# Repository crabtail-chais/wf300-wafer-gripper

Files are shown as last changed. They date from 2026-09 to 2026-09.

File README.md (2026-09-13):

# WF300 — 300 mm 双手晶圆夹取治具

Open hardware for a two-hand, edge-contact 300 mm wafer gripper.

**P1D1 工程试制设计 / Engineering prototype. 尚未完成实物资格验证，不能凭本仓库直接放行真实工艺晶圆使用。**

Assembly geometry — schematic only

本项目公开双手持握、水平低速转移晶圆的机械设计、尺寸图、BOM 和生产装配说明。它不是安全双手联锁，也不是 FOUP 取片器、吸盘或平桌铲片工具。

## 从哪里开始

1. 阅读 [安全边界与未关闭事项](SAFETY.md) 和 [公开版说明](docs/PUBLICATION.md)。
2. 查看 [12 页 A3 尺寸图](drawings/WF300-DH_P1D1_drawings.pdf) 与 [11 页生产装配说明](docs/WF300-DH_P1D1_assembly_manual.pdf)。
3. 下载 [闭合 FreeCAD 模型](cad/WF300-DH_P1D1_closed.FCStd)、[全开模型](cad/WF300-DH_P1D1_open.FCStd) 或 [闭合 STEP](cad/WF300-DH_P1D1_closed.step)。
4. 加工评审使用 [5 种自制件 STEP](parts_step)、[BOM](manufacturing/BOM_P1D1.csv)、[紧固连接记录](manufacturing/16个紧固连接与扭矩记录.csv) 和 [首件验收记录](manufacturing/首件验收记录.csv)。空白记录不代表合格。

## 设计边界

| 项目 | P1D1 基线 |
| --- | --- |
| 晶圆 | Ø300 mm；厚度 0.50–0.90 mm，参考片 0.775 mm |
| 接触 | 正反面最外缘 2 mm 内允许接触；四个未填充 PEEK 槽块 |
| 结构材料 | 6061-T651 框架、316L 导杆/端盖、A4-70 螺钉 |
| 采购件 | Ensinger TECAPEEK SX natural；igus JSM-1012-20；Lee Spring LP024K05S316；TE 31090 |
| 单侧行程 | 8 ± 0.20 mm，待首件检验 |
| 开启力目标 | 每手横向开启增量 2–5 N，峰值 ≤5 N；不含托举自重 |
| 洁净 / ESD 意图 | Class 100 左右 / ISO 5 操作区；金属独立接地、工位离子化；不是认证 |
| 使用假设 | 干态、水平、低速，20–25°C、40%–55% RH，无凝露、有防跌托盘 |

数值是需求、设计值或开发目标，不是实测合格结果。装配说明提供材料、表处、压装、线束、清洗、停点、检查及操作程序；任何代料或尺寸修改都需要重新验证。

## 文件组织

| 目录 | 内容 |
| --- | --- |
| `cad/` | 闭合 / 全开 FCStd 与 STEP，含简化采购件和参考晶圆 |
| `parts_step/` | 左右框架、槽块、导杆、端盖的局部坐标 STEP |
| `drawings/` | 12 页 PDF 及逐页 SVG / DXF |
| `manufacturing/` | 13 行 BOM、16 连接记录、首件验收表、公开来源链接 |
| `docs/` | 中文装配说明、版本范围与验证状态 |
| `tools/` | 无第三方依赖的只读文件校验工具，不是建模器或 CAM |
| `validation/` | 公开文件来源与哈希；不含内部详细测试记录 |

DXF 使用**纸面毫米**，标注由线、箭头和文字组成，不是关联式尺寸，不能直接当作 1:1 CAM。加工以经工程和工艺人员签署的关键二维尺寸、公差和要求为准，同版 STEP 补充复杂轮廓；矛盾需提偏差评审。

## 打开与校验

CAD 原件保留既有几何与对象结构。自制件为可编辑实体，不承诺完整草图约束或全参数生成历史。原生螺钉重算依赖 [FreeCAD Fasteners Workbench](https://github.com/shaise/FreeCAD_FastenersWB)，历史版本为 `79a06dc067b57ebc89532be835704eb2af5da96c`；没有该插件时，可使用 STEP 查看几何。

Python 3.10+，在仓库根目录运行：

```sh
python3 tools/verify_release.py
python3 -m unittest discover -s tests -v
```

这只检查发布文件、哈希、容器结构、BOM 数量及明显的本机路径/凭证模式，不会执行 CAD 内部 Python 对象，不会重算几何，也不会给制造、洁净、ESD 或晶圆安全放行。校验失败时退出码非零。

## 验证状态与贡献

装配说明引用了历史 CAD 检查结论；详细内部测试报告不属于本仓库的公开范围，因此不能仅凭本仓库独立复核这些历史结论。此次公开整理没有重跑依赖原工作环境的几何检查，也没有新增实片测试。详见 [验证状态](docs/VALIDATION.md)。

欢迎贡献制造可行性、人体工学、颗粒 / ESD 数据、减重设计和真正可重建的参数模型。请附版本、单位、假设、方法和原始证据，区分仿真与测量，见 [CONTRIBUTING](CONTRIBUTING.md)。

## 许可

项目权利范围内：硬件设计、图纸和 BOM 使用 **CERN-OHL-P-2.0**；独立软件使用 **MIT**；说明文档使用 **CC BY 4.0**。适用范围见 [LICENSING](LICENSING.md)，第三方工具和品牌见 [THIRD_PARTY_NOTICES](THIRD_PARTY_NOTICES.md)。均不构成供应商背书或适用性保证。

---

### English summary

WF300 is an unqualified engineering prototype for two-hand, horizontal handling of 300 mm wafers, 0.50–0.90 mm thick, with permitted contact within the outer 2 mm of both faces. It includes native FreeCAD files, STEP models, dimensioned drawings, a BOM, and Chinese manufacturing/assembly instructions. Cleanliness, ESD, operating forces, damage risk, and service life remain unqualified. Read [SAFETY](SAFETY.md) before any physical trial. The portable verifier checks release integrity, not mechanical safety. Hardware: CERN-OHL-P-2.0; software: MIT; documentation: CC BY 4.0, subject to the scope and third-party notices above.

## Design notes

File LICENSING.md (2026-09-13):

# Licence scope

Publication date: 2026-09-13. Project attribution: **crabtail-chais and contributors**.

The following licences apply to rights held by the project licensors. They do not relicense third-party software, standards, trademarks, catalogue documents or any rights the licensors do not hold.

| Files / material | Licence |
| --- | --- |
| `cad/`, `parts_step/`, `drawings/`, `manufacturing/` excluding `sources.json`; design geometry in `assets/` | [CERN-OHL-P-2.0](LICENSES/CERN-OHL-P-2.0.txt) |
| Project-authored `tools/`, `tests/` and any future project-authored CI configuration | [MIT](LICENSES/MIT.txt) |
| README, safety/contribution/publication/validation documentation, `validation/` records, `manufacturing/sources.json` | [CC BY 4.0](LICENSES/CC-BY-4.0.txt) |
| Licence texts, third-party notices and referenced external material | Their respective terms; see [notices](THIRD_PARTY_NOTICES.md) |

Copyright (c) 2026 crabtail-chais and contributors, to the extent copyright subsists and is held by those licensors. AI assistance was used in developing and documenting this engineering prototype; this notice does not assert exclusivity over public facts, standards, or non-copyrightable material.

The native FCStd files intentionally retain their exact historical bytes for model-to-drawing traceability. Their generic saved **“All rights reserved”** document property predates this release and is superseded, for the project-owned material in the files, by the explicit CERN-OHL-P-2.0 grant in this repository. This does not remove or override third-party rights. Carry this scope notice and applicable notices with redistributed source or products as required by the licences.

No endorsement by CERN, FreeCAD, tool developers, or suppliers is implied. Commercial reuse is allowed under the applicable licence conditions; there is no representation of patent clearance, cleanroom qualification, or fitness for a particular wafer process.

Licence references: [CERN official licence page](https://cern-ohl.web.cern.ch/), [Creative Commons BY 4.0](https://creativecommons.org/licenses/by/4.0/), [SPDX licence list](https://spdx.org/licenses/). Full texts are included under `LICENSES/`; the root `LICENSE` is the hardware licence.

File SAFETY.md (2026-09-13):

# 安全边界 / Safety and qualification status

**This is an unqualified engineering prototype, not a production-qualified wafer-handling device. CAD checks are not physical safety tests.**

截至 P1D1 发布基线，尚无实际首件测量、合格扭矩窗口、污染、晶圆损伤、ESD 或耐久验证结果。开源发布不改变工程准入状态。以下为工程警示和建议，不是在开源许可证之外增加用途限制。

## 制造与试验停点

- 图纸需由设计、加工、工艺和质量人员评审，尤其是表处后孔径、四点共面、PEEK 槽唇、端盖、有效螺纹和滑动配合。
- 0.08 / 0.20 / 0.15 N·m 是三类接头的试验起点，不是批准装配扭矩；需在同材料、表处和有效啮合条件下确定窗口。
- 弹簧、衬套和端子为简化几何，采购按准确料号和验收规范，不能制造这些包络体代替采购件。TE 端子实物接口和压接工艺仍需核验。
- 使用前须完成空载、假片厚度边界、偏载 / 单侧动作、力—行程、接头保持、颗粒、金属 / 离子污染及 ESD 检验。真实工艺片准入须现场责任人另行批准。
- 用防跌托盘及受控支撑进行试验；不得在悬空晶圆上调螺钉或拆弹簧。双手柄没有安全联锁功能。

## 不能从当前结果推导的结论

- 开启力 2–5 N/手不等于低自重或人体工学合格；持握载荷、疲劳、防滑、线束拖力需独立评估。
- Class 100 / ISO 5 是操作环境意图，未证明治具动态产尘符合要求。工艺污染限值仍需由实际使用方给定。
- 金属到公共点 ≤1 Ω、离子平衡与晶圆表面电位各 ±10 V 是开发目标。绝缘 PEEK / iglidur 不能单靠金属接地消电；离子器读数不等于晶圆读数；不承诺绝对 0 V。
- 合格接地路径需现场 ESD 负责人批准，不能短接人员腕带安全电阻。
- 100 / 1000 次是开发筛查节点，不是寿命额定值。
- 不覆盖热片、湿片、真空、竖直或冲击搬运、FOUP、平桌铲片与自动化设备联锁。

事故、损伤或污染异常时先让载台承托晶圆，停止并隔离治具。请以不含客户晶圆图像、工艺机密或个人信息的方式报告风险；敏感细节不要直接发到公开 issue。

Provided as-is, without warranty. The licences and notices describe the legal terms; this page records engineering limitations rather than certification.

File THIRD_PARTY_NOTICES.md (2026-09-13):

# Third-party provenance and exclusions

## CAD tooling

The historical engineering files were produced with FreeCAD / Open CASCADE. Sixteen ISO 4762 screw representations were generated using [FreeCAD Fasteners Workbench](https://github.com/shaise/FreeCAD_FastenersWB), commit `79a06dc067b57ebc89532be835704eb2af5da96c` (ScrewMaker: Ulrich Brammer; workbench wrapper: Shai Seger and contributors).

The upstream workbench [declares GPLv2](https://github.com/shaise/FreeCAD_FastenersWB/blob/79a06dc067b57ebc89532be835704eb2af5da96c/LICENSE). Its program source, icons and distributions are **not bundled or relicensed as MIT here**. The native files contain generated shapes, module/class references and serialized parameter data, not a vendored workbench implementation. Project licence grants are limited to project-controlled design rights; use of a GPL tool does not itself establish that every generated output is GPL-licensed. See upstream terms for the tool. No general legal clearance opinion is made.

Other development plugins, workstation-specific validator implementations and detailed historical test reports are not redistributed. Tool references in the assembly documentation are attribution, not endorsement of this project by those developers.

## Purchased components and standards

Ensinger, igus, Lee Spring, Bossard, TE Connectivity and Outokumpu names identify proposed materials or publicly documented components. They remain their owners' names and marks. No manufacturer has certified this assembly through this publication. Availability, price, exact screw order codes and suitability require independent confirmation.

Spring envelopes, installed bush dimensions and terminal tongues are project-made simplified representations, **not downloaded manufacturer CAD**. They omit physical details and are not production models for those purchased parts.

The repository links to public catalogue/standards sources in [sources.json](manufacturing/sources.json) and the assembly manual. It does not distribute supplier PDF originals, proprietary CAD downloads, ISO/SEMI standard texts, private quotations, supplier contact lists or internal budgets. Dimensions and factual source references do not grant rights to copy the linked documents.

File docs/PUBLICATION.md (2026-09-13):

# P1D1 公开版范围与历史文档勘误

公开版整理日期：2026-09-13。设计版次仍为 **P1D1**，不是新的机械修订版。

## 未改变的内容

2 个 FCStd、2 个装配 STEP、5 个自制件 STEP、24 个带标注 SVG / DXF、12 页图纸 PDF、11 页装配说明 PDF、装配说明 Markdown 和制造表单均保留原件字节。没有重画、减重或改变尺寸、公差、采购选型及安全门槛。逐项原始和发布哈希见 [provenance.json](../validation/provenance.json)。

FCStd 内历史默认许可证字段未修改，以免破坏其已有哈希绑定；项目权利人的本次显式开源授权及优先适用说明见 [LICENSING](../LICENSING.md)。

## 新增和脱敏

新增公开 README、安全边界、许可、第三方来源说明、贡献指南、只读校验工具和测试。公开范围限于设计、图纸、BOM、装配说明、许可及可移植代码。详细内部测试结果、数值校验报告和历史日志未纳入，文件来源表也不索引这些未公开报告；不改写失败为通过。

## 阅读历史装配说明时的适用说明

原 PDF / Markdown 中关于 `source/`、`evidence/`、`qa/`、旧会话、初次失败截图以及“没有对外发送”的文字描述的是**工程交付时点**，不代表当前仓库的目录、可复现性或发布状态。本说明对公开目录和复现范围的描述优先；机械技术要求未被改写。

| 历史描述 | 公开版实际内容 |
| --- | --- |
| `source/` 可复现流程 | 旧生成器依赖历史会话、本机插件及固定路径，首版不纳入。原生 CAD 是当前设计源文件；不是从零参数重建承诺。 |
| `evidence/`、`qa/` 及初次失败截图 | 不在公开范围；只保留文件来源 / 哈希及验证状态说明。装配说明中的历史检查结论不等于本仓库提供了完整的公开复核证据。 |
| 原始投影 SVG | 仅保留逐页带尺寸图和装配等轴预览，不纳入庞大中间投影数据。 |
| 旧 R2、选型中间版、询价 / 预算材料 | 不属于首个公开基线，避免版本混用和内部商业信息披露。 |

历史几何验证的范围和不能推出的结论见 [VALIDATION](VALIDATION.md)。本次公开 QA 只决定文件是否适合公开，不是机械制造或真实晶圆使用批准。

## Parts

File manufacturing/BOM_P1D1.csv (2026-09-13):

item | part_number | description | quantity | material_source
01 | WF300-P1-FRAME-L | 左框架 | 1 | 6061-T651 / CNC，批准加工厂
02 | WF300-P1-FRAME-R | 右框架 | 1 | 6061-T651 / CNC，批准加工厂
03 | WF300-P1-PAD | 槽块 | 4 | TECAPEEK SX natural / Ensinger原料
04 | WF300-P1-ROD | 阶梯导杆 | 2 | 316L / CNC+精磨，材料批次证明
05 | WF300-P1-CAP | 叉形端盖 | 4 | 316L / 一体车铣
06 | JSM-1012-20 | 导向衬套 | 4 | igus / iglidur J
07 | LP024K05S316 | 压缩弹簧 | 4 | Lee Spring / Type316 ASTM A313
08 | ISO4762-M3x12 | 槽块螺钉 | 8 | A4-70 / Bossard BN612优先
09 | ISO4762-M4x10 | 端盖螺钉 | 4 | A4-70 / Bossard BN612优先
10 | ISO4762-M3x6 | 接地螺钉 | 4 | A4-70 / Bossard BN612优先
11 | TE 31090 | 治具端子 | 4 | TE SOLISTRAND / 铜镀锡
12 | WF300-P1-WIRE | 接地线材裁件 | 4 | 22AWG PTFE，1000±20 / 按规范采购
13 | TE 31090 | 远端端子 | 4 | TE / 线束远端，不在CAD内

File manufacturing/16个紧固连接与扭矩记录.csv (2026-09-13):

joint | object | type | spec | contact | thread_host | nominal_engagement_mm | test_start_Nm | approved_torque_window | actual_torque_Nm | operator | tool_id | inspection | recheck_24h | recheck_1000cycles
J01 | CAP_SCREW_1_L | K2 | M4x10 | END_COLLAR_1_L | GUIDE_ROD_1 | 7 | 0.2 | 未实测/不得当作起始扭矩直接放行
J02 | CAP_SCREW_1_R | K2 | M4x10 | END_COLLAR_1_R | GUIDE_ROD_1 | 7 | 0.2 | 未实测/不得当作起始扭矩直接放行
J03 | CAP_SCREW_2_L | K2 | M4x10 | END_COLLAR_2_L | GUIDE_ROD_2 | 7 | 0.2 | 未实测/不得当作起始扭矩直接放行
J04 | CAP_SCREW_2_R | K2 | M4x10 | END_COLLAR_2_R | GUIDE_ROD_2 | 7 | 0.2 | 未实测/不得当作起始扭矩直接放行
J05 | GROUND_SCREW_FRAME_L | K3 | M3x6 | GROUND_LUG_FRAME_L | LEFT_CARRIAGE | 5.16 | 0.15 | 未实测/不得当作起始扭矩直接放行
J06 | GROUND_SCREW_FRAME_R | K3 | M3x6 | GROUND_LUG_FRAME_R | RIGHT_CARRIAGE | 5.16 | 0.15 | 未实测/不得当作起始扭矩直接放行
J07 | GROUND_SCREW_ROD_1 | K3 | M3x6 | GROUND_LUG_ROD_1 | GUIDE_ROD_1 | 5.16 | 0.15 | 未实测/不得当作起始扭矩直接放行
J08 | GROUND_SCREW_ROD_2 | K3 | M3x6 | GROUND_LUG_ROD_2 | GUIDE_ROD_2 | 5.16 | 0.15 | 未实测/不得当作起始扭矩直接放行
J09 | PAD_SCREW_01_1 | K1 | M3x12 | PEEK_PAD_01 | RIGHT_CARRIAGE | 4 | 0.08 | 未实测/不得当作起始扭矩直接放行
J10 | PAD_SCREW_01_2 | K1 | M3x12 | PEEK_PAD_01 | RIGHT_CARRIAGE | 4 | 0.08 | 未实测/不得当作起始扭矩直接放行
J11 | PAD_SCREW_02_1 | K1 | M3x12 | PEEK_PAD_02 | RIGHT_CARRIAGE | 4 | 0.08 | 未实测/不得当作起始扭矩直接放行
J12 | PAD_SCREW_02_2 | K1 | M3x12 | PEEK_PAD_02 | RIGHT_CARRIAGE | 4 | 0.08 | 未实测/不得当作起始扭矩直接放行
J13 | PAD_SCREW_03_1 | K1 | M3x12 | PEEK_PAD_03 | LEFT_CARRIAGE | 4 | 0.08 | 未实测/不得当作起始扭矩直接放行
J14 | PAD_SCREW_03_2 | K1 | M3x12 | PEEK_PAD_03 | LEFT_CARRIAGE | 4 | 0.08 | 未实测/不得当作起始扭矩直接放行
J15 | PAD_SCREW_04_1 | K1 | M3x12 | PEEK_PAD_04 | LEFT_CARRIAGE | 4 | 0.08 | 未实测/不得当作起始扭矩直接放行
J16 | PAD_SCREW_04_2 | K1 | M3x12 | PEEK_PAD_04 | LEFT_CARRIAGE | 4 | 0.08 | 未实测/不得当作起始扭矩直接放行

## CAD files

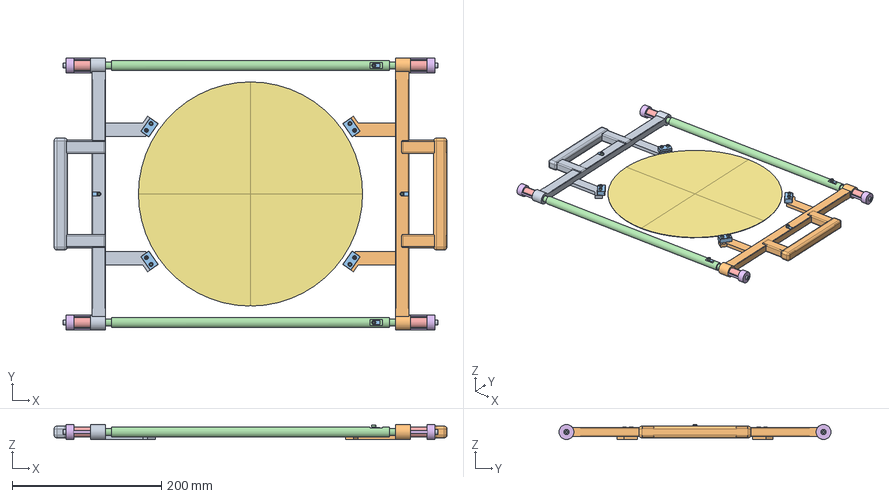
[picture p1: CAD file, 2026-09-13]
cad/WF300-DH_P1D1_open.step
526.0 x 364.0 x 20.0 mm
Left handle-carriage
Right handle-carriage
PEEK edge-capture pad 1
PEEK edge-capture pad 2
PEEK edge-capture pad 3
PEEK edge-capture pad 4
P1 one-piece stepped rod 1
LP024K05S316 1L — simplified envelope, NOT coil CAD
LP024K05S316 1R — simplified envelope, NOT coil CAD
R2 forked cap 1-L / positive opening stop
R2 forked cap 1-R / positive opening stop
P1 one-piece stepped rod 2
LP024K05S316 2L — simplified envelope, NOT coil CAD
LP024K05S316 2R — simplified envelope, NOT coil CAD
R2 forked cap 2-L / positive opening stop
R2 forked cap 2-R / positive opening stop
Reference wafer — 300 mm
M3x12-Screw x 8
M4x10-Screw
M4x10-Screw010
M4x10-Screw011
M4x10-Screw012
BUSH_1_L
BUSH_2_L
BUSH_1_R
BUSH_2_R
GROUND_LUG_FRAME_L
M3x6-Screw x 2
GROUND_LUG_FRAME_R
GROUND_LUG_ROD_1
M3x6-Screw005
GROUND_LUG_ROD_2
M3x6-Screw006

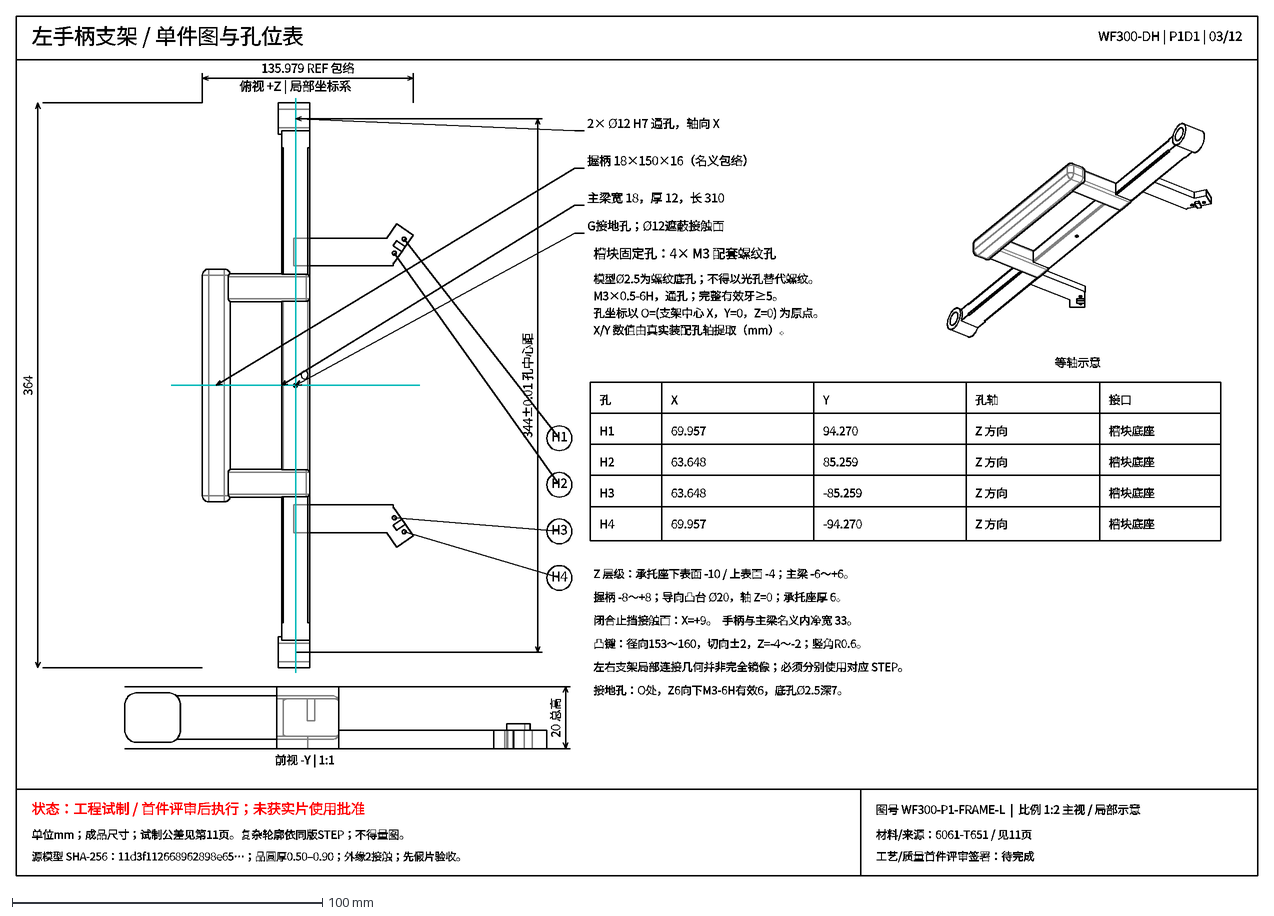
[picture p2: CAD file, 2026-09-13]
drawings/03_WF300-P1-FRAME-L.dxf
左手柄支架 / 单件图与孔位表
WF300-DH | P1D1 | 03/12
状态：工程试制 / 首件评审后执行；未获实片使用批准
单位mm；成品尺寸；试制公差见第11页。复杂轮廓依同版STEP；不得量图。
源模型 SHA-256：11d3f112668962898e65…；晶圆厚0.50–0.90；外缘2接触；先假片验收。
图号 WF300-P1-FRAME-L | 比例 1:2 主视 / 局部示意
材料/来源：6061-T651 / 见11页
工艺/质量首件评审签署：待完成
俯视 +Z | 局部坐标系
364
344±0.01 孔中心距
135.979 REF 包络
O
2× Ø12 H7 通孔，轴向 X
握柄 18×150×16（名义包络）
主梁宽 18，厚 12，长 310
20 总高
前视 -Y | 1:1
等轴示意
槽块固定孔：4× M3 配套螺纹孔
模型Ø2.5为螺纹底孔；不得以光孔替代螺纹。
M3×0.5-6H，通孔；完整有效牙≥5。
孔坐标以 O=(支架中心 X，Y=0，Z=0) 为原点。
X/Y 数值由真实装配孔轴提取（mm）。
孔
X
Y
孔轴
接口
H1
69.957
94.270
Z 方向
槽块底座
H2
63.648
85.259
H3
-85.259
H4
-94.270
Z 层级：承托座下表面 -10 / 上表面 -4；主梁 -6～+6。
握柄 -8～+8；导向凸台 Ø20，轴 Z=0；承托座厚 6。
闭合止挡接触面：X=+9。 手柄与主梁名义内净宽 33。
凸键：径向153～160，切向±2，Z=-4～-2；竖角R0.6。
左右支架局部连接几何并非完全镜像；必须分别使用对应 STEP。
接地孔：O处，Z6向下M3-6H有效6，底孔Ø2.5深7。
G接地孔；Ø12遮蔽接触面

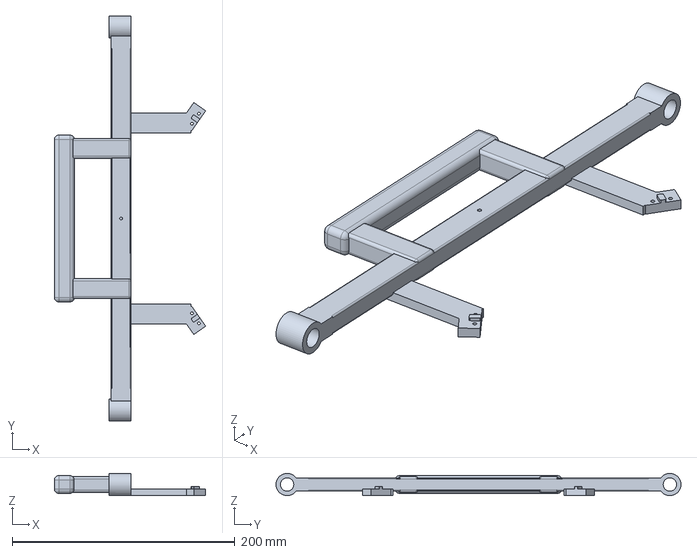
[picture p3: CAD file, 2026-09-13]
parts_step/WF300_left_P1D1.step
136.0 x 364.0 x 20.0 mm

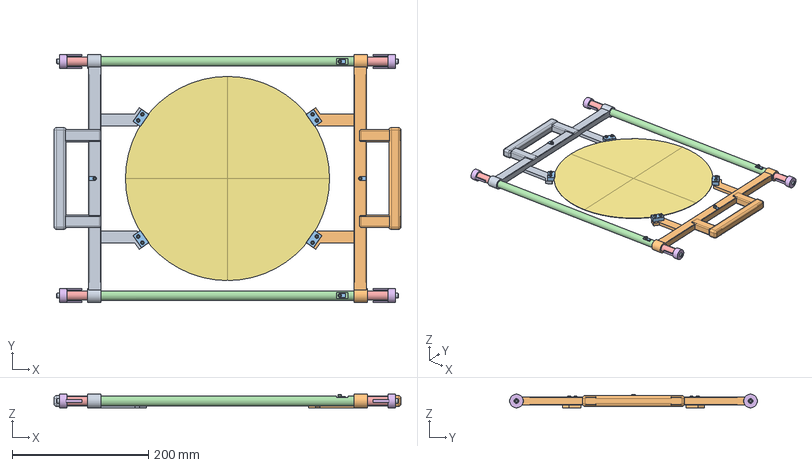
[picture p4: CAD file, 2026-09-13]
cad/WF300-DH_P1D1_closed.step
510.0 x 364.0 x 20.0 mm
Left handle-carriage
Right handle-carriage
PEEK edge-capture pad 1
PEEK edge-capture pad 2
PEEK edge-capture pad 3
PEEK edge-capture pad 4
P1 one-piece stepped rod 1
LP024K05S316 1L — simplified envelope, NOT coil CAD
LP024K05S316 1R — simplified envelope, NOT coil CAD
R2 forked cap 1-L / positive opening stop
R2 forked cap 1-R / positive opening stop
P1 one-piece stepped rod 2
LP024K05S316 2L — simplified envelope, NOT coil CAD
LP024K05S316 2R — simplified envelope, NOT coil CAD
R2 forked cap 2-L / positive opening stop
R2 forked cap 2-R / positive opening stop
Reference wafer — 300 mm
M3x12-Screw
M3x12-Screw022
M3x12-Screw023
M3x12-Screw024
M3x12-Screw025
M3x12-Screw026
M3x12-Screw027
M3x12-Screw028
M4x10-Screw
M4x10-Screw010
M4x10-Screw011
M4x10-Screw012
BUSH_1_L
BUSH_2_L
BUSH_1_R
BUSH_2_R
GROUND_LUG_FRAME_L
M3x6-Screw
GROUND_LUG_FRAME_R
M3x6-Screw004
GROUND_LUG_ROD_1
M3x6-Screw005
GROUND_LUG_ROD_2
M3x6-Screw006

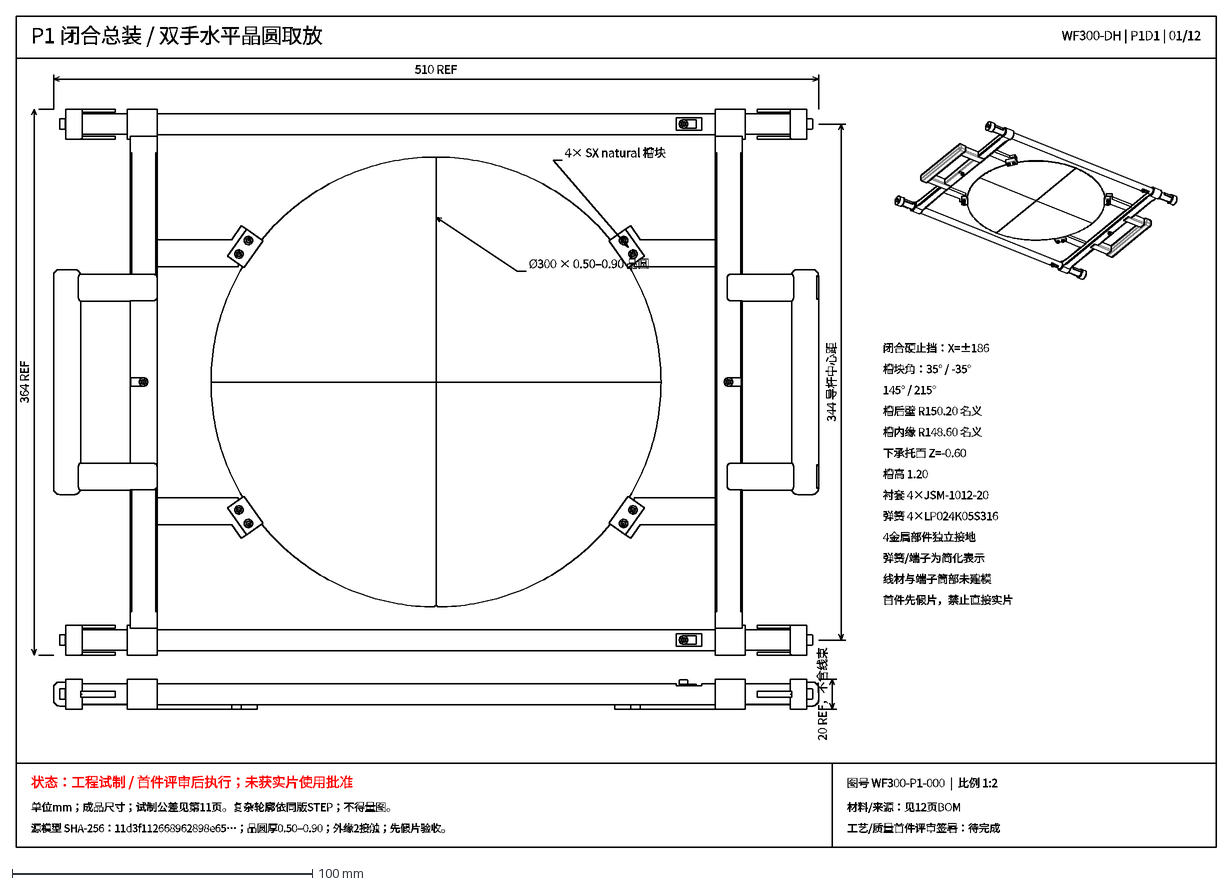
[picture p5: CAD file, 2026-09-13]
drawings/01_WF300-P1-000.dxf
P1 闭合总装 / 双手水平晶圆取放
WF300-DH | P1D1 | 01/12
状态：工程试制 / 首件评审后执行；未获实片使用批准
单位mm；成品尺寸；试制公差见第11页。复杂轮廓依同版STEP；不得量图。
源模型 SHA-256：11d3f112668962898e65…；晶圆厚0.50–0.90；外缘2接触；先假片验收。
图号 WF300-P1-000 | 比例 1:2
材料/来源：见12页BOM
工艺/质量首件评审签署：待完成
510 REF
364 REF
344 导杆中心距
Ø300 × 0.50–0.90 晶圆
4× SX natural 槽块
闭合硬止挡：X=±186
槽块角：35° / -35°
145° / 215°
槽后壁 R150.20 名义
槽内缘 R148.60 名义
下承托面 Z=-0.60
槽高 1.20
衬套 4×JSM-1012-20
弹簧 4×LP024K05S316
4金属部件独立接地
弹簧/端子为简化表示
线材与端子筒部未建模
首件先假片，禁止直接实片
20 REF，不含线束

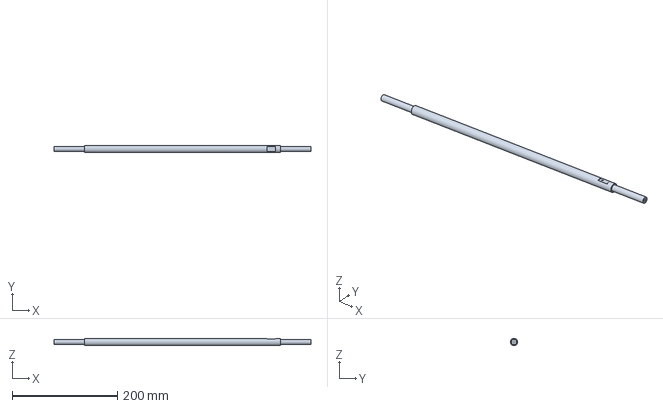
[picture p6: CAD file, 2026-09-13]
parts_step/WF300_rod_P1D1.step
488.0 x 14.0 x 14.0 mm

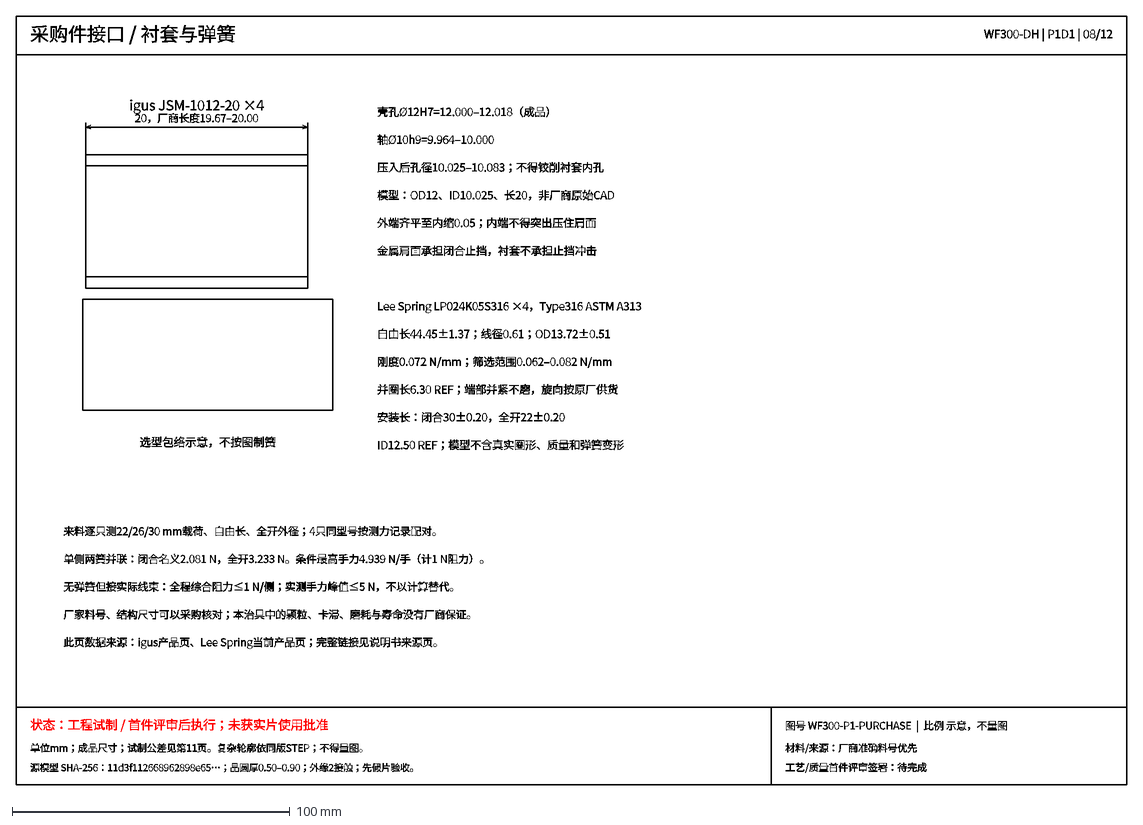
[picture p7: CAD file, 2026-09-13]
drawings/08_WF300-P1-PURCHASE.dxf
采购件接口 / 衬套与弹簧
WF300-DH | P1D1 | 08/12
状态：工程试制 / 首件评审后执行；未获实片使用批准
单位mm；成品尺寸；试制公差见第11页。复杂轮廓依同版STEP；不得量图。
源模型 SHA-256：11d3f112668962898e65…；晶圆厚0.50–0.90；外缘2接触；先假片验收。
图号 WF300-P1-PURCHASE | 比例 示意，不量图
材料/来源：厂商准确料号优先
工艺/质量首件评审签署：待完成
igus JSM-1012-20 ×4
20，厂商长度19.67–20.00
壳孔Ø12H7=12.000–12.018（成品）
轴Ø10h9=9.964–10.000
压入后孔径10.025–10.083；不得铰削衬套内孔
模型：OD12、ID10.025、长20，非厂商原始CAD
外端齐平至内缩0.05；内端不得突出压住肩面
金属肩面承担闭合止挡，衬套不承担止挡冲击
选型包络示意，不按图制簧
Lee Spring LP024K05S316 ×4，Type316 ASTM A313
自由长44.45±1.37；线径0.61；OD13.72±0.51
刚度0.072 N/mm；筛选范围0.062–0.082 N/mm
并圈长6.30 REF；端部并紧不磨，旋向按原厂供货
安装长：闭合30±0.20，全开22±0.20
ID12.50 REF；模型不含真实圈形、质量和弹簧变形
来料逐只测22/26/30 mm载荷、自由长、全开外径；4只同型号按测力记录配对。
单侧两簧并联：闭合名义2.081 N，全开3.233 N。条件最高手力4.939 N/手（计1 N阻力）。
无弹簧但接实际线束：全程综合阻力≤1 N/侧；实测手力峰值≤5 N，不以计算替代。
厂家料号、结构尺寸可以采购核对；本治具中的颗粒、卡滞、磨耗与寿命没有厂商保证。
此页数据来源：igus产品页、Lee Spring当前产品页；完整链接见说明书来源页。

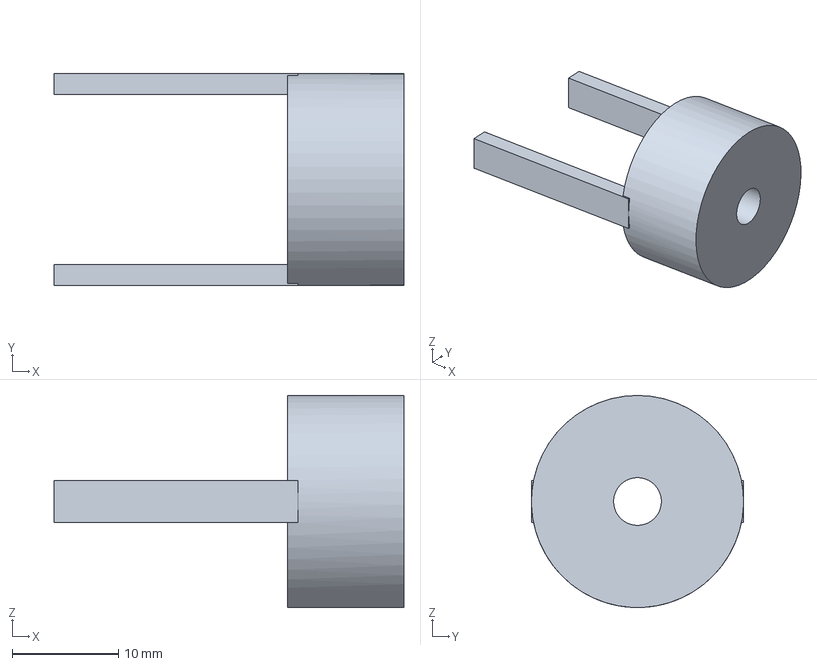
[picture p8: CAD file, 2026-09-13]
parts_step/WF300_cap_P1D1.step
33.0 x 20.0 x 20.0 mm

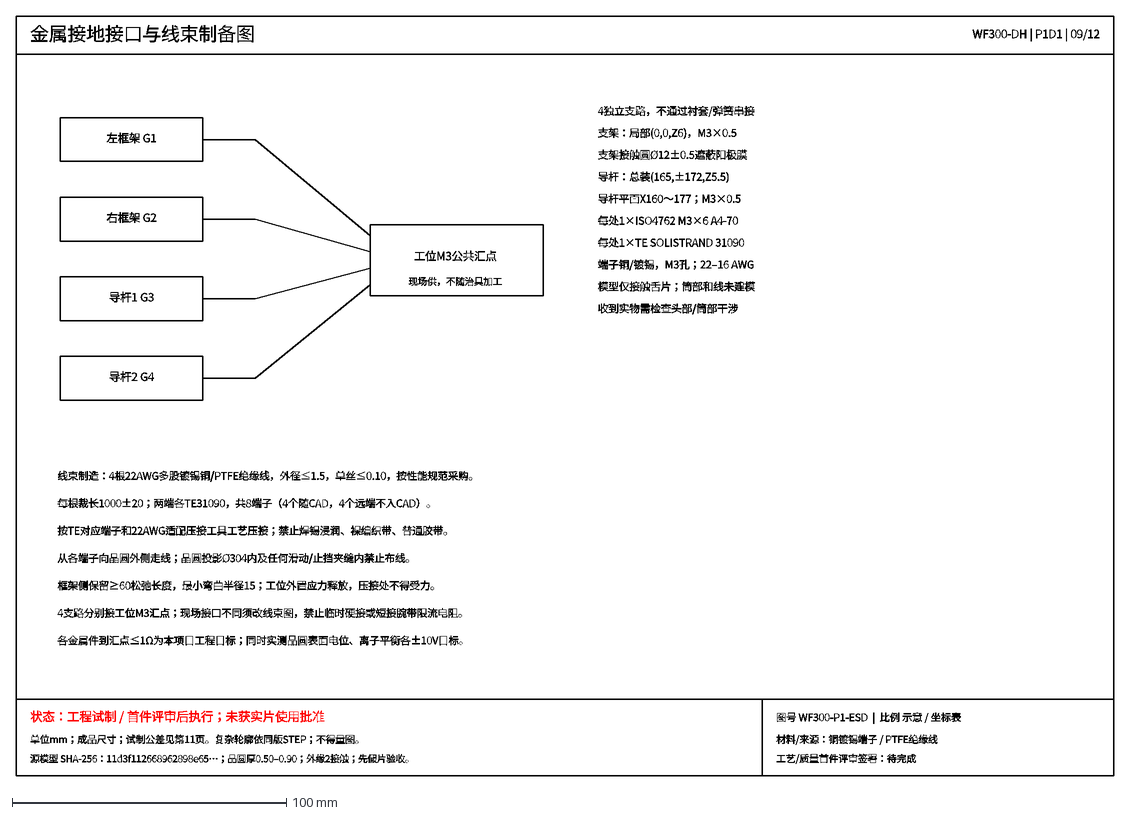
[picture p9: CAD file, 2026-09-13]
drawings/09_WF300-P1-ESD.dxf
金属接地接口与线束制备图
WF300-DH | P1D1 | 09/12
状态：工程试制 / 首件评审后执行；未获实片使用批准
单位mm；成品尺寸；试制公差见第11页。复杂轮廓依同版STEP；不得量图。
源模型 SHA-256：11d3f112668962898e65…；晶圆厚0.50–0.90；外缘2接触；先假片验收。
图号 WF300-P1-ESD | 比例 示意 / 坐标表
材料/来源：铜镀锡端子 / PTFE绝缘线
工艺/质量首件评审签署：待完成
左框架 G1
右框架 G2
导杆1 G3
导杆2 G4
工位M3公共汇点
现场供，不随治具加工
4独立支路，不通过衬套/弹簧串接
支架：局部(0,0,Z6)，M3×0.5
支架接触圆Ø12±0.5遮蔽阳极膜
导杆：总装(165,±172,Z5.5)
导杆平面X160～177；M3×0.5
每处1×ISO4762 M3×6 A4-70
每处1×TE SOLISTRAND 31090
端子铜/镀锡，M3孔；22–16 AWG
模型仅接触舌片；筒部和线未建模
收到实物需检查头部/筒部干涉
线束制造：4根22AWG多股镀锡铜/PTFE绝缘线，外径≤1.5，单丝≤0.10，按性能规范采购。
每根裁长1000±20；两端各TE31090，共8端子（4个随CAD，4个远端不入CAD）。
按TE对应端子和22AWG适配压接工具工艺压接；禁止焊锡浸润、裸编织带、普通胶带。
从各端子向晶圆外侧走线；晶圆投影Ø304内及任何滑动/止挡夹缝内禁止布线。
框架侧保留≥60松弛长度，最小弯曲半径15；工位外置应力释放，压接处不得受力。
4支路分别接工位M3汇点；现场接口不同须改线束图，禁止临时硬接或短接腕带限流电阻。
各金属件到汇点≤1Ω为本项目工程目标；同时实测晶圆表面电位、离子平衡各±10V目标。

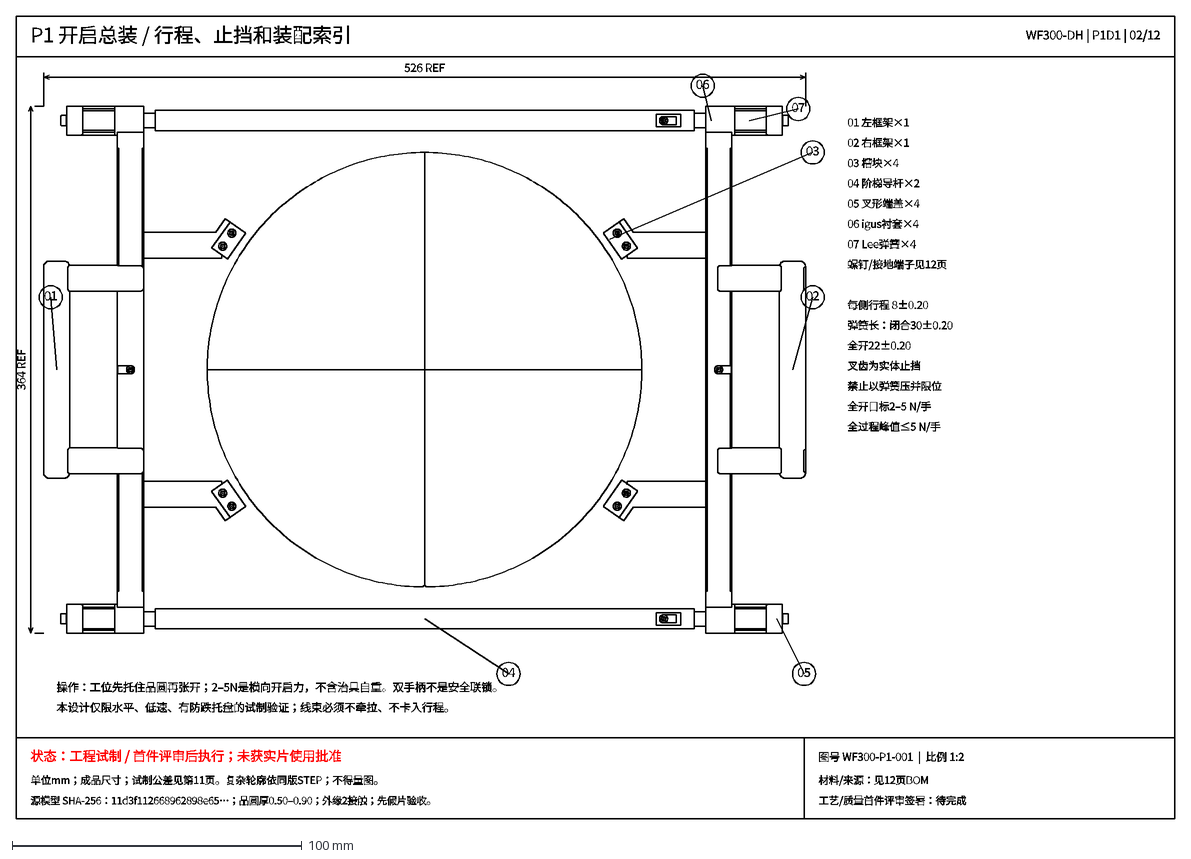
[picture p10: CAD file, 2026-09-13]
drawings/02_WF300-P1-001.dxf
P1 开启总装 / 行程、止挡和装配索引
WF300-DH | P1D1 | 02/12
状态：工程试制 / 首件评审后执行；未获实片使用批准
单位mm；成品尺寸；试制公差见第11页。复杂轮廓依同版STEP；不得量图。
源模型 SHA-256：11d3f112668962898e65…；晶圆厚0.50–0.90；外缘2接触；先假片验收。
图号 WF300-P1-001 | 比例 1:2
材料/来源：见12页BOM
工艺/质量首件评审签署：待完成
526 REF
364 REF
01
02
03
04
05
06
07
01 左框架×1
02 右框架×1
03 槽块×4
04 阶梯导杆×2
05 叉形端盖×4
06 igus衬套×4
07 Lee弹簧×4
螺钉/接地端子见12页
每侧行程 8±0.20
弹簧长：闭合30±0.20
全开22±0.20
叉齿为实体止挡
禁止以弹簧压并限位
全开目标2–5 N/手
全过程峰值≤5 N/手
操作：工位先托住晶圆再张开；2–5N是横向开启力，不含治具自重。双手柄不是安全联锁。
本设计仅限水平、低速、有防跌托盘的试制验证；线束必须不牵拉、不卡入行程。

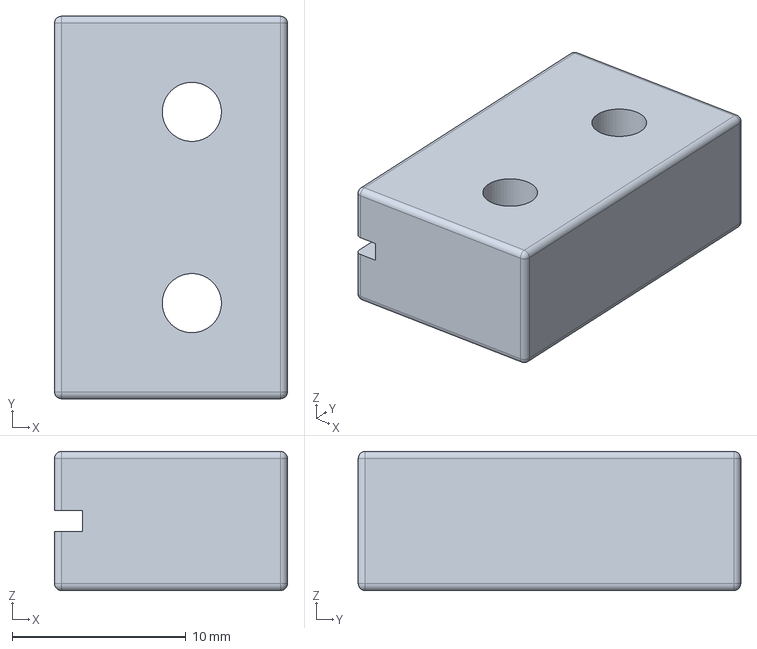
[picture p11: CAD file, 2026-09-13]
parts_step/WF300_pad_P1D1.step
13.4 x 22.0 x 8.00 mm

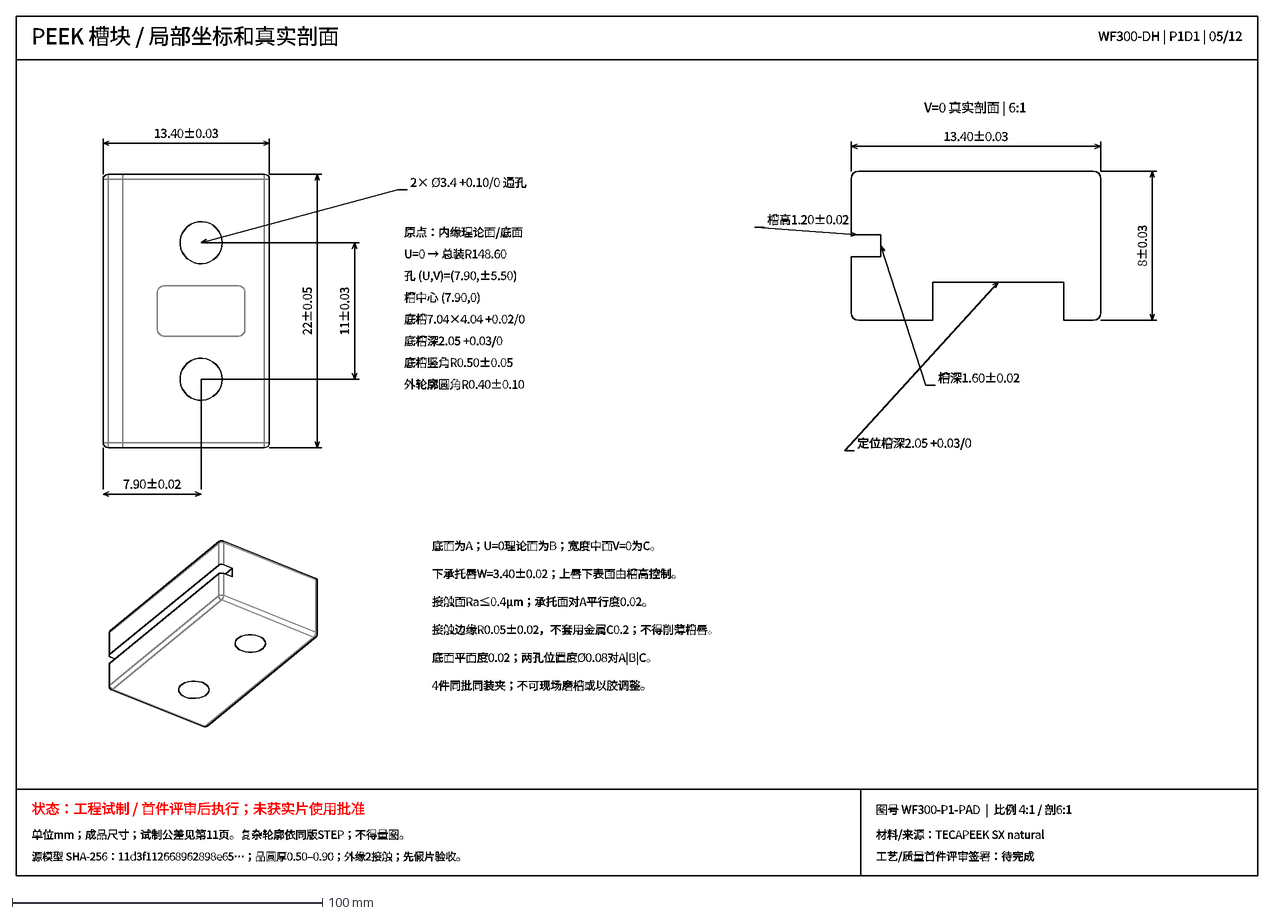
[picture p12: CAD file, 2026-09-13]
drawings/05_WF300-P1-PAD.dxf
PEEK 槽块 / 局部坐标和真实剖面
WF300-DH | P1D1 | 05/12
状态：工程试制 / 首件评审后执行；未获实片使用批准
单位mm；成品尺寸；试制公差见第11页。复杂轮廓依同版STEP；不得量图。
源模型 SHA-256：11d3f112668962898e65…；晶圆厚0.50–0.90；外缘2接触；先假片验收。
图号 WF300-P1-PAD | 比例 4:1 / 剖6:1
材料/来源：TECAPEEK SX natural
工艺/质量首件评审签署：待完成
13.40±0.03
22±0.05
7.90±0.02
11±0.03
2× Ø3.4 +0.10/0 通孔
原点：内缘理论面/底面
U=0 → 总装R148.60
孔 (U,V)=(7.90,±5.50)
槽中心 (7.90,0)
底槽7.04×4.04 +0.02/0
底槽深2.05 +0.03/0
底槽竖角R0.50±0.05
外轮廓圆角R0.40±0.10
V=0 真实剖面 | 6:1
8±0.03
槽深1.60±0.02
槽高1.20±0.02
定位槽深2.05 +0.03/0
底面为A；U=0理论面为B；宽度中面V=0为C。
下承托唇W=3.40±0.02；上唇下表面由槽高控制。
接触面Ra≤0.4μm；承托面对A平行度0.02。
接触边缘R0.05±0.02，不套用金属C0.2；不得削薄槽唇。
底面平面度0.02；两孔位置度Ø0.08对A|B|C。
4件同批同装夹；不可现场磨槽或以胶调整。

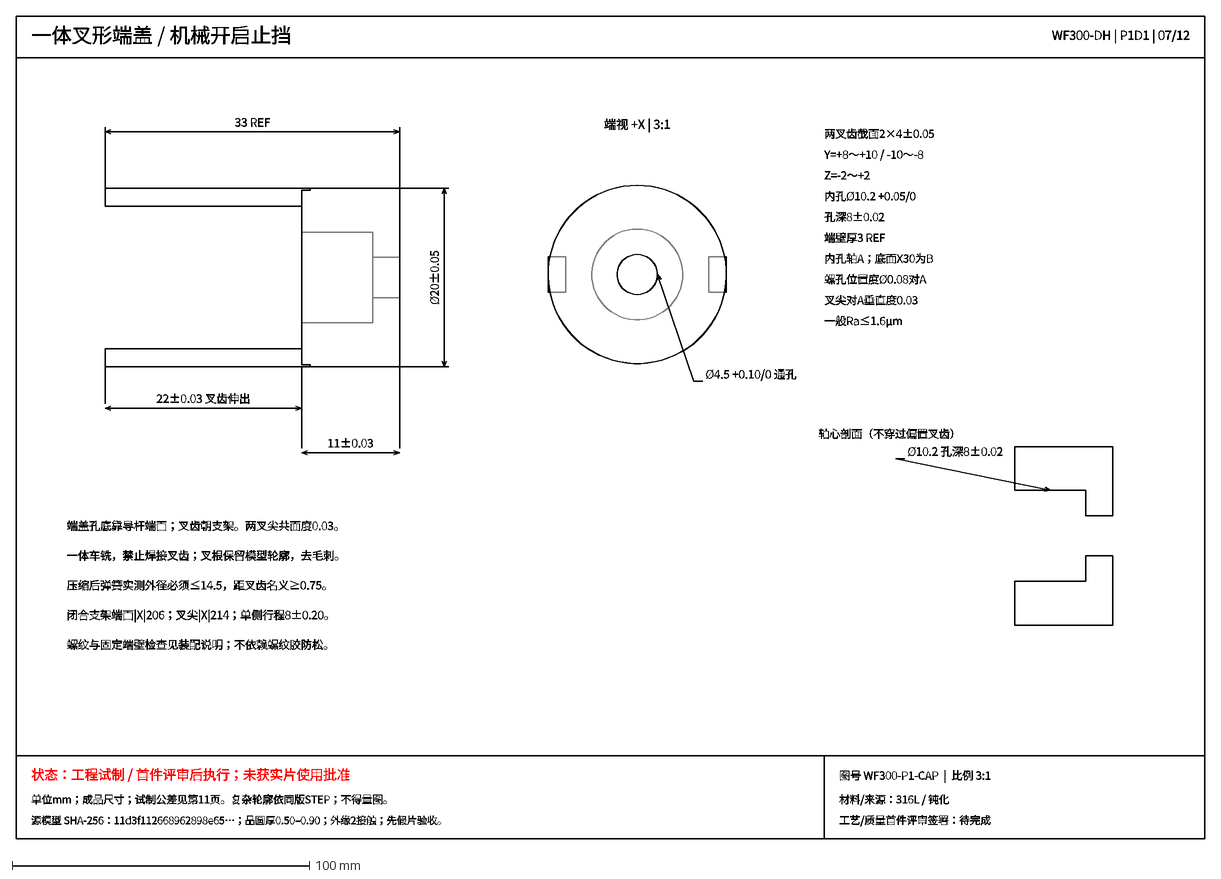
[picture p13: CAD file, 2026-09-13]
drawings/07_WF300-P1-CAP.dxf
一体叉形端盖 / 机械开启止挡
WF300-DH | P1D1 | 07/12
状态：工程试制 / 首件评审后执行；未获实片使用批准
单位mm；成品尺寸；试制公差见第11页。复杂轮廓依同版STEP；不得量图。
源模型 SHA-256：11d3f112668962898e65…；晶圆厚0.50–0.90；外缘2接触；先假片验收。
图号 WF300-P1-CAP | 比例 3:1
材料/来源：316L / 钝化
工艺/质量首件评审签署：待完成
33 REF
22±0.03 叉齿伸出
11±0.03
Ø20±0.05
端视 +X | 3:1
Ø4.5 +0.10/0 通孔
两叉齿截面2×4±0.05
Y=+8～+10 / -10～-8
Z=-2～+2
内孔Ø10.2 +0.05/0
孔深8±0.02
端壁厚3 REF
内孔轴A；底面X30为B
螺孔位置度Ø0.08对A
叉尖对A垂直度0.03
一般Ra≤1.6μm
轴心剖面（不穿过偏置叉齿）
Ø10.2 孔深8±0.02
端盖孔底靠导杆端面；叉齿朝支架。两叉尖共面度0.03。
一体车铣，禁止焊接叉齿；叉根保留模型轮廓，去毛刺。
压缩后弹簧实测外径必须≤14.5，距叉齿名义≥0.75。
闭合支架端面|X|206；叉尖|X|214；单侧行程8±0.20。
螺纹与固定端壁检查见装配说明；不依赖螺纹胶防松。

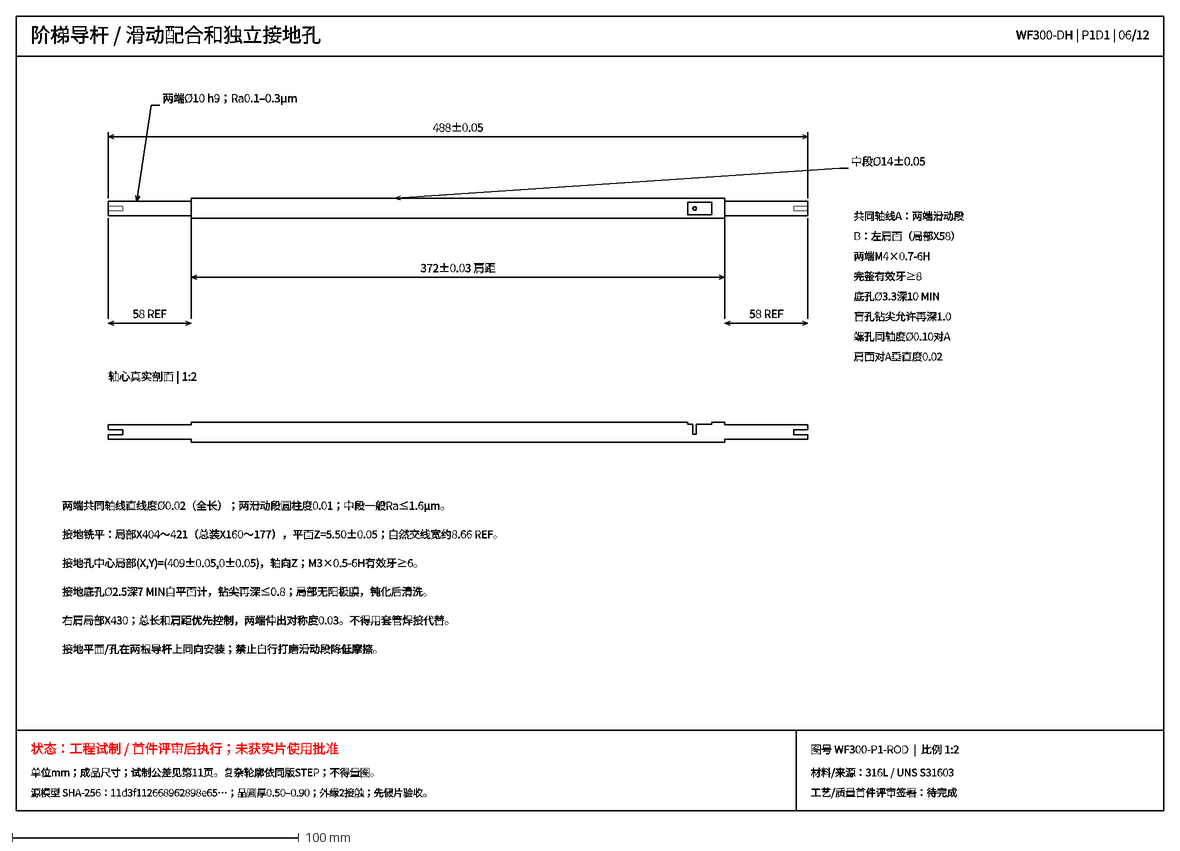
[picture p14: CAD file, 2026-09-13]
drawings/06_WF300-P1-ROD.dxf
阶梯导杆 / 滑动配合和独立接地孔
WF300-DH | P1D1 | 06/12
状态：工程试制 / 首件评审后执行；未获实片使用批准
单位mm；成品尺寸；试制公差见第11页。复杂轮廓依同版STEP；不得量图。
源模型 SHA-256：11d3f112668962898e65…；晶圆厚0.50–0.90；外缘2接触；先假片验收。
图号 WF300-P1-ROD | 比例 1:2
材料/来源：316L / UNS S31603
工艺/质量首件评审签署：待完成
488±0.05
372±0.03 肩距
58 REF
中段Ø14±0.05
两端Ø10 h9；Ra0.1–0.3μm
共同轴线A：两端滑动段
B：左肩面（局部X58）
两端M4×0.7-6H
完整有效牙≥8
底孔Ø3.3深10 MIN
盲孔钻尖允许再深1.0
螺孔同轴度Ø0.10对A
肩面对A垂直度0.02
轴心真实剖面 | 1:2
两端共同轴线直线度Ø0.02（全长）；两滑动段圆柱度0.01；中段一般Ra≤1.6μm。
接地铣平：局部X404～421（总装X160～177），平面Z=5.50±0.05；自然交线宽约8.66 REF。
接地孔中心局部(X,Y)=(409±0.05,0±0.05)，轴向Z；M3×0.5-6H有效牙≥6。
接地底孔Ø2.5深7 MIN自平面计，钻尖再深≤0.8；局部无阳极膜，钝化后清洗。
右肩局部X430；总长和肩距优先控制，两端伸出对称度0.03。不得用套管焊接代替。
接地平面/孔在两根导杆上同向安装；禁止自行打磨滑动段降低摩擦。

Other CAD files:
parts_step/WF300_right_P1D1.step
drawings/12_WF300-P1-BOM.dxf
drawings/04_WF300-P1-FRAME-R.dxf
drawings/10_WF300-P1-JOINTS.dxf
cad/WF300-DH_P1D1_closed.FCStd
cad/WF300-DH_P1D1_open.FCStd
drawings/11_WF300-P1-TOL.dxf

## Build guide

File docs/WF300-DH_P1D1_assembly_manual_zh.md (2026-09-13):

# WF300-DH P1D1 工程试制生产与装配说明

2026-09-13；首件评审后执行，未经真实工艺晶圆资格放行。

## 01 / 交付状态与操作边界

本版已更新P1模型并输出12张尺寸图。可用于加工厂工艺评审与工程首件准备；工艺/质量完成图纸评审、接头试验和首件检查后执行样机装配。不是量产放行图，也不允许凭CAD通过直接夹取真实工艺晶圆。

| 项目 | 执行条件 |
| --- | --- |
| 用户已确认 | Ø300 mm；厚0.50–0.90 mm；正反面外缘2 mm允许接触；洁净室真实工艺片；现场离子化及ESD接地点可用。 |
| 本版工程选取 | 室温20–25°C，40%–55%RH、无凝露，干态、水平、低速、有防跌托盘的转移。温湿度为本次选取，不冒充原始用户要求。 |
| 排除工况 | 热片、湿片、真空、竖直夹持、冲击、FOUP取放、平桌铲片、真空吸附、自动设备联锁。双手柄不构成安全双手联锁。 |
| 简化范围 | 弹簧仅安装包络；衬套为压入后名义尺寸；TE端子仅接触舌片，压接筒/导线未建模。均非厂商原始CAD，不可按简化体制造采购件。 |
| 保留基线 | R2D1原文件未改。新会话wf300-dh-p1-20260913；12页二维图P1D1必须与本版STEP/CAD配套。 |
| 尚无的证据 | 实测扭矩窗口、手力/摩擦、颗粒污染、清洗效果、晶圆损伤、ESD及寿命记录。空白记录表不表示合格。 |

### 同版绑定

闭合模型SHA-256：11d3f112668962898e65137bf57b7d0899ca1fd1fa94e9139c2dc14f936bb964

闭合与全开各931项自动CAD检查通过，16个紧固件逐个入库；补充功能与非配合件干涉检查另附。程序曾误将接地孔排在端部螺孔之前，本包保留初次失败证据和本地候选排序修正的6项回归测试。未降低任何安全阈值，未改已安装插件；该修正不构成对软件的整体验证。

## 02 / 文件使用与制造基线

| 位置 | 内容与用途 |
| --- | --- |
| 二维图PDF | 12张A3图：闭合、全开、左右框架、槽块、导杆、端盖、衬套弹簧、接地、紧固连接、公差、BOM。 |
| drawings/ | 每张带标注DXF和SVG；另有原始投影SVG。DXF为纸面mm，不可当作1:1 CAM。尺寸为线/箭头/文字，非关联式DIMENSION。 |
| parts_step/ | 左右框架、槽块、导杆、端盖共5种自制件STEP，局部坐标；复杂轮廓制造参考。 |
| cad/ | 闭合和全开FCStd与STEP。装配中含参考晶圆和简化采购件；不可用包络体积算弹簧重量。 |
| manufacturing/ | BOM、16连接记录、首件检查、来源和生产说明。记录须由实际操作者填写，保留原始测量文件。 |
| evidence/、qa/ | 模型哈希、检查报告/截图、投影数据、STEP回读比对、文件完整性和排版证据。 |
| source/ | 本次可复现建模、投影、绘图、验证流程及依赖说明，不是加工机床程序。 |

### 制造权威顺序

经签署的二维关键尺寸/公差和技术要求优先，同版STEP补充未逐段标注的复杂外轮廓。差异必须开偏差单，不可自行取较宽松值。模型省略真实螺纹牙形、部分工艺倒角/钻尖、采购件自由态；加工按二维要求，禁把底孔当成成品光孔。

第11页未注公差、表面和基准属于本次工程设计值，需由加工厂进行能力评审。制造公差不等于CAD校核的0.001mm/0.001mm³数值容差。左右框架历史连接轮廓不完全镜像，禁止只加工一种后镜像套用。

在20±2°C稳定后检尺寸；量具不确定度应不超过被测公差带的20%作为本项目检验要求。PEEK装夹力不得引入可见弹性变形；关键接触尺寸需低测力测量并记录方法。

## 03 / BOM、材料与采购验收

| 项/数量 | 规格 | 采购/制造要求 |
| --- | --- | --- |
| 01 / 1 | WF300-P1-FRAME-L | 6061-T651 / CNC，批准加工厂 |
| 02 / 1 | WF300-P1-FRAME-R | 6061-T651 / CNC，批准加工厂 |
| 03 / 4 | WF300-P1-PAD | TECAPEEK SX natural / Ensinger原料 |
| 04 / 2 | WF300-P1-ROD | 316L / CNC+精磨，材料批次证明 |
| 05 / 4 | WF300-P1-CAP | 316L / 一体车铣 |
| 06 / 4 | JSM-1012-20 | igus / iglidur J |
| 07 / 4 | LP024K05S316 | Lee Spring / Type316 ASTM A313 |
| 08 / 8 | ISO4762-M3x12 | A4-70 / Bossard BN612优先 |
| 09 / 4 | ISO4762-M4x10 | A4-70 / Bossard BN612优先 |
| 10 / 4 | ISO4762-M3x6 | A4-70 / Bossard BN612优先 |
| 11 / 4 | TE 31090 | TE SOLISTRAND / 铜镀锡 |
| 12 / 4 | WF300-P1-WIRE | 22AWG PTFE，1000±20 / 按规范采购 |
| 13 / 4 | TE 31090 | TE / 线束远端，不在CAD内 |
CAD装机件表示40个，参考晶圆1个；另4根线材及4个远端端子不在CAD。推荐备件见图12。没有下单、没有确认库存或交期；Bossard BN612是优先系列，M3/M4准确订单代码以A4-70和尺寸实物核对，不得将A4-70写成316L。

来料须有材质/状态/炉批或聚合物批号、准确品牌料号、尺寸/表处/清洗符合性文件。Ensinger只指PEEK原料来源，不冒充已承接本件加工；框架和钢件加工厂待采购批准。任何代料、涂层或弹簧换型必须重新评审。

## 04 / 自制件加工工序

| 对象 | 工序与关键控制 |
| --- | --- |
| 左右框架 | 6061-T651整料→粗铣→按供方工艺稳定化评估→建立A座面/B导孔/C止挡基准→同装夹精加工两导孔、键和孔坐标→M3攻丝→去毛刺→遮蔽→无染料阳极15±5μm、无镍封孔→清洗→成品复测。 |
| 框架遮蔽 | Ø12H7导孔全长、全部螺纹孔和局部O处顶面Ø12接地圆。座面/键尺寸为表处后尺寸，需预留膜层；不允许现场随意打磨修配。端子接触区保持无膜并作连续性复检。 |
| PEEK槽块 | TECAPEEK SX natural同批原料→底面/外形→通孔→槽口和底部键槽→受控去毛刺→接触面/边缘检验→独立清洗、保护槽唇。不得改用碳填充料或涂层。 |
| 阶梯导杆 | 316L棒料→车中段、肩面和端段→端部M4孔→铣接地平面并攻M3→滑动段精磨10h9、Ra0.1–0.3→倒角/钝化→清洗→直线度、肩距、有效牙和接地平面检验。 |
| 叉形端盖 | 316L一体车铣；孔底、内孔轴、叉尖需同基准关联。不得焊接叉齿或靠切短叉齿调行程。验内孔深8、叉长22、两尖共面及端壁。 |
| 棱边/盲孔 | 一般金属棱边C0.2±0.1；PEEK接触边R0.05±0.02。刀具半径、倒角或钻尖与关键尺寸有冲突时停止，不以隐藏特征为由自行扩大。 |
所有加工及脏装配在洁净操作区外完成。粗糙度须用可比方法记录，不能用“抛光”替代数值要求。零件标识放非接触、非配合、非导电接触区域；标记不得产生残留颗粒或溶剂污染。

## 05 / 衬套、弹簧与接地线束

### 压装衬套

每框架2只JSM-1012-20。检壳孔12.000–12.018后，用平头压头和刚性支撑同轴压入；禁止敲击、胶粘、加油或压后铰孔。外端齐平至内缩0.05，内端不得突出妨碍金属止挡。压后内径10.025–10.083，检查裂纹、翻边与滑动阻力。

### 弹簧逐只筛选

4只LP024K05S316同料号、Type316 ASTM A313；L0=44.45±1.37，k=0.072N/mm，筛选范围0.062–0.082。测22/26/30mm力值与压缩外径；外径≤14.5为本治具来料装配要求，不是原厂保证。禁止截短、磨端、拉长或换刚度救卡滞。

两簧并联/侧：名义闭合2.081N、全开3.233N。按自由长/刚度及安装长±0.20预算，最小闭合1.597N，最大开位弹簧合力3.939N。加1N综合阻力得到4.939N仅条件估算。杆/盖重量相关粗筛阻力已接近1N，必须实测静摩擦及线束拖力，不能宣称计算已验证。

### 4支路线束制备

2–5N/手指横向开启增量，不含支撑治具自重的负荷。首件须另外称重，并由佩戴洁净手套的实际操作者评估持握、疲劳及防滑；不能以小开启力推断人体工学合格。

4根22AWG多股镀锡铜、PTFE绝缘线，成品外径≤1.5mm、单丝≤0.10mm、裁长1000±20mm；每根两端各TE31090，合计8端子。线材按本性能规范采购，供方提交结构及批次资料，不虚构精确线材SKU。

TE31090公开目录给出M3螺柱、22–16AWG、宽5.54、长11.40、料厚0.84、筒内径最小1.65mm。铜镀锡端子选择有污染风险，置于外缘之外且需清洗/见证片验证；不宣称适合所有前道工序。其简化舌片眼孔3.18和眼心距2.77是装配建模假定，实物不符合则先改单，禁止改孔凑装。

由合格线束商按TE对应端子/22AWG的适配压接工具和工艺执行，记录工具、模具、压接拉脱验收和剥线长度；无对应有效工艺时不得自制压接。禁止裸编织带、浸锡、普通胶带及暴露散股。远端接现场M3汇点；接口不同须调整线束图。

线从各接点向晶圆外侧引出；Ø304晶圆投影区和滑动止挡夹缝内禁入，最小弯曲半径15mm，框架侧松弛长度≥60mm。现场独立应力释放，线不承重也不拉端子；实际净空和阻力必须在全行程检查。

## 06 / 生产装配工步与停点

| 步 | 执行动作 | 检查/停点 |
| --- | --- | --- |
| A00 | 核对同版图、BOM、序号/批次/清洗和量具；移走真实晶圆。 | 工艺/质量评审签署；无签署先评审。 |
| A01 | 按第5页在框架外压装4衬套。 | 记录内径/齐平/裂纹；不合格停。 |
| A02 | 工装保持双杆344中心距、接地平面朝上；两框架从两端同步套入。 | Ø14中段不可穿衬套；不强拧拉正。 |
| A03 | 无弹簧状态保持双手实际承重姿态；装接地端子和实际线束。 | 全行程综合起动/回程阻力≤1N/侧；超限先排查。 |
| A04 | 四PEEK槽朝内、按35/-35/145/215°落座；键不顶底。8个M3分步对称锁紧。 | 先用同材试件确定K1窗口；记录四点共面/槽尺寸。 |
| A05 | 已测力配对弹簧分别套轴端；用保持工装限制弹出。 | 核四只料号和测力表，装后无触轴/叉齿。 |
| A06 | 4端盖叉齿朝内，孔底靠杆端；装M4×10。 | K2窗口先验证；有效牙/不顶底/防弹出。 |
| A07 | G1–G4各用M3×6夹端子；所有支路独立接现场汇点。 | K3窗口验证；全行程连续性≤1Ω；不短接腕带电阻。 |
| A08 | 慢速空行程，测开闭端点、两手力曲线。 | 8±0.20；闭合30±0.20/开位22±0.20；每手全开2–5N，峰值≤5N。 |
| A09 | 完成清洗、记录和假片分阶段循环。 | 见第8–9页；不能跳到真实片。 |
异常：先由工位托住晶圆，再停止并隔离治具。悬空持片时不得调螺钉、强掰、甩动或拔接地线。弹簧拆卸须无片、有保持工具、逐只受控卸载。维护拆装后重做关键几何、力与颗粒/ESD检查。

## 07 / 16连接清单与扭矩验证

| 编号 | CAD连接名 | 规格 / 类别 | 名义啮合 |
| --- | --- | --- | --- |
| J01 | CAP_SCREW_1_L | M4x10 / K2 | 7mm |
| J02 | CAP_SCREW_1_R | M4x10 / K2 | 7mm |
| J03 | CAP_SCREW_2_L | M4x10 / K2 | 7mm |
| J04 | CAP_SCREW_2_R | M4x10 / K2 | 7mm |
| J05 | GROUND_SCREW_FRAME_L | M3x6 / K3 | 5.16mm |
| J06 | GROUND_SCREW_FRAME_R | M3x6 / K3 | 5.16mm |
| J07 | GROUND_SCREW_ROD_1 | M3x6 / K3 | 5.16mm |
| J08 | GROUND_SCREW_ROD_2 | M3x6 / K3 | 5.16mm |
| J09 | PAD_SCREW_01_1 | M3x12 / K1 | 4mm |
| J10 | PAD_SCREW_01_2 | M3x12 / K1 | 4mm |
| J11 | PAD_SCREW_02_1 | M3x12 / K1 | 4mm |
| J12 | PAD_SCREW_02_2 | M3x12 / K1 | 4mm |
| J13 | PAD_SCREW_03_1 | M3x12 / K1 | 4mm |
| J14 | PAD_SCREW_03_2 | M3x12 / K1 | 4mm |
| J15 | PAD_SCREW_04_1 | M3x12 / K1 | 4mm |
| J16 | PAD_SCREW_04_2 | M3x12 / K1 | 4mm |
K1：PEEK/铝，试验起点0.08N·m；K2：端盖/杆，起点0.20N·m；K3：端子/金属，起点0.15N·m。它们不是批准扭矩。先用同批材料、表处和有效牙接头试验确定窗口，再填入工艺卡后装配。

确认落座、防转、无压痕裂纹/滑牙/咬死；24小时和100/1000次循环复检。至少保留3个同材试验连接/类别的记录作为P1筛查，不把样本量当作统计认证。禁止直接加胶、加垫圈或换紧固件解决松动。

## 08 / 清洗、洁净与静电控制

| 对象 | 实施方法与验收边界 |
| --- | --- |
| 清洗起始路线 | 同批见证样验证：经现场认可的中性低残留清洗剂去残留→高纯DI充分漂洗→过滤氮气或批准方法干燥→目视/显微、颗粒和离子残留检查。药剂浓度/温度/时间需依材料兼容性及现场规范定，不凭空给通用配方。 |
| 禁用/隔离 | 不混洗PEEK与带毛刺金属；不用硅油、喷涂润滑剂、抛光膏/普通胶带。不得对装有衬套的总成擅自烘烤或强超声。 |
| 洁净空气 | Class100意图按ISO5操作区准备；空气等级按ISO14644-1及现场采样计划测定。单件材料或供应商系列页不证明整机动态ISO5。 |
| 晶圆污染 | 做空白/空载/持假片动作对比，统一采样量/方法并记录基线。新增颗粒、金属和离子污染阈值由工艺负责人提供；没有阈值不可给合格结论。 |
| 金属导电 | G1–G4各金属部件至现场公共点≤1Ω为工程连续性目标，覆盖全行程；不靠衬套、弹簧、氧化膜或滑动面通电。现场ESD负责人批准与公共点的连接。 |
| 绝缘体离子化 | PEEK/iglidur绝缘表面无法仅靠金属接地消电。工位持续离子化覆盖，工作位离子平衡±10V目标；晶圆表面电位另测，目标绝对值≤10V。 |
| 测量记录 | 仪器型号/校准、量程/距离、晶圆膜层/厚度、动作阶段、温湿度和测量不确定度。±10V为开发目标，不是器件损伤阈值，也不承诺绝对0V。 |
| 包装 | 合格后使用现场批准低析出双层洁净袋；避开槽唇受力，标识序号、版次、批次、清洗日期。开包/移交规程由现场质量负责。 |

## 09 / 首件验收、操作与维护

| 阶段 | 数量/动作 | 通过条件 |
| --- | --- | --- |
| 尺寸 | 1台关键尺寸100%；5种自制件全尺寸记录 | 图纸尺寸、粗糙度、螺纹、衬套压入及材料表处均有记录。 |
| 动作 | 空载先100次，再1000次开发耐久筛查 | 无裂纹、松动、卡滞、可见屑；0/100/1000次复测力、行程和接地。不是寿命额定值。 |
| 厚度边界 | 0.50/0.775/0.90mm各1假片，先测直径和翘曲，再各100次取放 | 四点承托，接触均限外缘2mm，显微对比无新增崩边/划痕；不在悬空调节。 |
| 单侧/偏载 | 无片先慢速单侧先开、合理手持偏载和线束扰动 | 能受控恢复，无卡滞/夹线；不做自由跌落或猛烈松手。 |
| 污染/ESD | 同现场、代表膜层和实际动作，空白对照 | 按第8页阈值与原始测量判定；任一无阈值或未测即未通过。 |
| 使用准入 | 设计、工艺、质量、使用方逐项签署 | 先批准代表性监控/非良品，再按现场流程决定真实工艺片。当前未获得这些批准。 |

### 操作顺序

取片：片在合适载台上支撑→双手受控张开→水平对准外缘→缓慢闭合至金属止挡→确认4点有效承托→小行程试抬→水平转移。放片：载台充分承托→缓慢张开→退出。不得让闭合弹簧冲击晶圆边缘。

### 每班前与维护后

确认端盖/螺钉无松动、槽唇无缺损、衬套不移位、线束无损、离子化和接地量测有效。任何肉眼可见屑、异常阻力、电位超限、划伤或碰撞立即隔离并记录。不要在晶圆上方拆件。维护后需清洗及重验；未建立验证周期前每次使用前检查。

## 10 / 首件记录与未关闭事项

| 号 | 对象 | 验收要求 | 方法 |
| --- | --- | --- | --- |
| I01 | 壳孔4处 | 12.000–12.018mm；两孔344±0.01 | 孔径规/CMM |
| I02 | 衬套4处 | 装后孔10.025–10.083；外端内缩0–0.05 | 低测力内径/深度 |
| I03 | 杆滑动面 | 9.964–10.000；Ra0.1–0.3μm | 外径千分尺/粗糙度 |
| I04 | 杆肩距/总长 | 372±0.03 / 488±0.05 | CMM/长度量仪 |
| I05 | PEEK槽 | 高1.20±0.02；深1.60±0.02 | 光学/低测力 |
| I06 | 定位键槽 | 图5/11；侧隙0.02–0.04，顶隙0.05–0.10 | 组合尺寸算术检查 |
| I07 | 闭合功能尺寸 | 槽后壁R150.20±0.10；内缘R148.60±0.10；共面0.05 | CMM/专用量规 |
| I08 | 单侧行程/簧长 | 8±0.20；30±0.20/22±0.20 | 位移表 |
| I09 | 阻力/手力 | 无簧综合≤1N/侧；全开2–5N/手；峰值≤5N | 力传感器+位移记录 |
| I10 | 等电位/电位 | 4支路≤1Ω；离子平衡和晶圆电位各±10V目标 | 连续性/电位量测 |
| I11 | 污染/损伤 | 按现场批准限值；无新增崩边/划痕 | 空白和动作见证片 |
| I12 | 接头/清洗 | 16连接窗口/实际扭矩、24h及循环复检；清洗有效 | 独立工艺卡/原始数据 |
工艺停点：实际螺钉扭矩窗口、TE实物接口和线束压接工艺、现场污染阈值/清洗参数、真实晶圆直径翘曲与膜层。需实物和现场证据关闭，不由进一步CAD计算代签。先完成制造评审再加工首件；完整量产放行仍未完成。

## 11 / 来源索引与变更追溯

S01 Ensinger TECAPEEK SX natural — 半导体级未填充 PEEK 原料身份；不证明本治具工艺合格

[Ensinger TECAPEEK SX natural](https://www.ensingerplastics.com/en/shapes/peek-tecapeek-sx-natural)

S02 igus JSM-1012-20 — 10×12×20 衬套、压入后孔径、壳孔和轴公差；官网公开页面读取

[igus JSM-1012-20](https://www.igus.eu/iglidur-ibh/sleeve-bearings/product-details/iglidur-j-m?artnr=JSM-1012-20)

S03 igus J 材料技术数据 — Ra 0.1-0.3 μm、对钢动摩擦系数0.06-0.18；不是本治具静摩擦保证值

[igus J 材料技术数据](https://www.igus.com/info/material-iglidur-j?C=ES&L=es)

S04 Lee Spring LP 024K 05 S316 — 首选弹簧准确料号、材料、尺寸、公差；官网直接读取

[Lee Spring LP 024K 05 S316](https://www.leespring.com/product/compression-spring-lp024k05s316-stainless-steel-type-316)

S05 Lee Spring LP 024K 04 S316 — 较短候选弹簧对比，最终不选

[Lee Spring LP 024K 04 S316](https://www.leespring.com/product/compression-spring-lp024k04s316-stainless-steel-type-316)

S06 Lee Spring official catalog — 历史目录纸页47/PDF第49页交叉核对，不作为当期库存或交期证明

[Lee Spring official catalog](https://www.leespring.com/sites/default/files/2019-07/Lee_Spring_Catalog_US_Eng.pdf)

S07 Bossard BN 612 — ISO4762全牙A4系列；具体SKU及A4-70证书需订单确认，非316L承诺

[Bossard BN 612](https://www.bossard.com/at-de/eshop/schrauben-mit-innenantrieb/zylinderschrauben-mit-innensechskant-ohne-schaft/p/612/)

S08 Outokumpu Supra 316L/4404 — 316L/S31603/1.4404身份识别，不证明棒料已购或加工商已批准

[Outokumpu Supra 316L/4404](https://www.outokumpu.com/en/products/product-ranges/supra/supra-316l-4404)

S09 ESDA Principles of ESD Control — 导体等电位与绝缘体离子化的区别；本文±10V为工程目标，非该标准限值

[ESDA Principles of ESD Control](https://www.esda.org/esd-overview/esd-fundamentals/part-2-principles-of-esd-control/)

S10 ISO 14644-14:2026 public scope — 设备空气粒子适用性评价；不替代晶圆颗粒、ESD、材料或清洗资格

[ISO 14644-14:2026 public scope](https://www.iso.org/standard/91615.html)

S11 FreeCAD Fasteners Workbench — 现有16颗ISO4762 CAD几何来源；commit 79a06dc067b57ebc89532be835704eb2af5da96c，非实物供应商

[FreeCAD Fasteners Workbench](https://github.com/shaise/FreeCAD_FastenersWB)

S12 Lee Spring spring diameter expansion note — 压缩会改变弹簧外径，需叠加自由态外径公差；不可只验名义包络

[Lee Spring spring diameter expansion note](https://www.leespring.com/sites/default/files/pdf/Lee%20Spring%20-%20WhitePaper%20-%20Spring%20Design%20General%20Consideration_US.pdf)

S13 TE SOLISTRAND 1773464-2 QRG — 31090目录尺寸、材料和接线范围；非洁净室认证

[TE SOLISTRAND 1773464-2 QRG](https://www.te.com/content/dam/te-com/documents/industrial-automation-and-control/global/1773464-2_QRG_SOLISTRAND_08-2013.pdf)

检索：STEP.parts对JSM、Lee Spring以及新增31090返回0条；本地核验目录为空。结构化未命中不等于市场不存在。转用厂商官网参数，经用户“允许简化模型，继续出图”授权制作明确标识的简化表示，未绕过下载验证码。

主要P1改动：壳孔10.10→12H7，加入4衬套；选定K05弹簧；4专用接地点及4端子/4螺钉；材料/工艺条件、公差和记录表配套。旧R2留存。没有对外发送图纸、询价或采购。

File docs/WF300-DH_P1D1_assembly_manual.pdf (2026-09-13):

WF300-DH | P1D1 | 2026-09-13 | 工程试制 / 非实片资格放行 | 1

# 01 / 交付状态与操作边界

## 本版已更新P1模型并输出12张尺寸图。可用于加工厂工艺评审与工程首件准备；工艺/质量完成图纸评审、接 头试验和首件检查后执行样机装配。不是量产放行图，也不允许凭CAD通过直接夹取真实工艺晶圆。

项目 | 执行条件
用户已确认 | Ø300 mm；厚0.50–0.90 mm；正反面外缘2 mm允许接触；洁净室真实工艺片；现场离子化及ESD接地点可用。
本版工程选取 | 室温20–25°C，40%–55%RH、无凝露，干态、水平、低速、有防跌托盘的转移。温湿度为本次选取，不冒充原 始用户要求。
排除工况 | 热片、湿片、真空、竖直夹持、冲击、FOUP取放、平桌铲片、真空吸附、自动设备联锁。双手柄不构成安全双 手联锁。
简化范围 | 弹簧仅安装包络；衬套为压入后名义尺寸；TE端子仅接触舌片，压接筒/导线未建模。均非厂商原始CAD，不可按 简化体制造采购件。
保留基线 | R2D1原文件未改。新会话wf300-dh-p1-20260913；12页二维图P1D1必须与本版STEP/CAD配套。
尚无的证据 | 实测扭矩窗口、手力/摩擦、颗粒污染、清洗效果、晶圆损伤、ESD及寿命记录。空白记录表不表示合格。

## 同版绑定

闭合模型SHA-256：11d3f112668962898e65137bf57b7d0899ca1fd1fa94e9139c2dc14f936bb964

### 闭合与全开各931项自动CAD检查通过，16个紧固件逐个入库；补充功能与非配合件干涉检查另附。程序曾误将接地孔 排在端部螺孔之前，本包保留初次失败证据和本地候选排序修正的6项回归测试。未降低任何安全阈值，未改已安装插件 ；该修正不构成对软件的整体验证。

# 02 / 文件使用与制造基线

位置 | 内容与用途
二维图PDF | 12张A3图：闭合、全开、左右框架、槽块、导杆、端盖、衬套弹簧、接地、紧固连接、公差、BOM。
drawings/ | 每张带标注DXF和SVG；另有原始投影SVG。DXF为纸面mm，不可当作1:1 CAM。尺寸为线/箭头/文字，非关 联式DIMENSION。
parts_step/ | 左右框架、槽块、导杆、端盖共5种自制件STEP，局部坐标；复杂轮廓制造参考。
cad/ | 闭合和全开FCStd与STEP。装配中含参考晶圆和简化采购件；不可用包络体积算弹簧重量。
manufacturing/ | BOM、16连接记录、首件检查、来源和生产说明。记录须由实际操作者填写，保留原始测量文件。
evidence/、qa/ | 模型哈希、检查报告/截图、投影数据、STEP回读比对、文件完整性和排版证据。
source/ | 本次可复现建模、投影、绘图、验证流程及依赖说明，不是加工机床程序。

## 制造权威顺序

### 经签署的二维关键尺寸/公差和技术要求优先，同版STEP补充未逐段标注的复杂外轮廓。差异必须开偏差单，不可自行 取较宽松值。模型省略真实螺纹牙形、部分工艺倒角/钻尖、采购件自由态；加工按二维要求，禁把底孔当成成品光孔。

### 第11页未注公差、表面和基准属于本次工程设计值，需由加工厂进行能力评审。制造公差不等于CAD校核的 0.001mm/0.001mm³数值容差。左右框架历史连接轮廓不完全镜像，禁止只加工一种后镜像套用。

### 在20±2°C稳定后检尺寸；量具不确定度应不超过被测公差带的20%作为本项目检验要求。PEEK装夹力不得引入可见弹 性变形；关键接触尺寸需低测力测量并记录方法。

# 03 / BOM、材料与采购验收

项/数量 | 规格 | 采购/制造要求
01 / 1 | WF300-P1-FRAME-L | 6061-T651 / CNC，批准加工厂
02 / 1 | WF300-P1-FRAME-R | 6061-T651 / CNC，批准加工厂
03 / 4 | WF300-P1-PAD | TECAPEEK SX natural / Ensinger原料
04 / 2 | WF300-P1-ROD | 316L / CNC+精磨，材料批次证明
05 / 4 | WF300-P1-CAP | 316L / 一体车铣
06 / 4 | JSM-1012-20 | igus / iglidur J
07 / 4 | LP024K05S316 | Lee Spring / Type316 ASTM A313
08 / 8 | ISO4762-M3x12 | A4-70 / Bossard BN612优先
09 / 4 | ISO4762-M4x10 | A4-70 / Bossard BN612优先
10 / 4 | ISO4762-M3x6 | A4-70 / Bossard BN612优先
11 / 4 | TE 31090 | TE SOLISTRAND / 铜镀锡
12 / 4 | WF300-P1-WIRE | 22AWG PTFE，1000±20 / 按规范采购
13 / 4 | TE 31090 | TE / 线束远端，不在CAD内

CAD装机件表示40个，参考晶圆1个；另4根线材及4个远端端子不在CAD。推荐备件见图12。没有下单、没有确认库存或交期；Bossard BN612是优先系列，M3/M4准确订单代码以A4-70和尺寸实物核对，不得将A4-70写成316L。

来料须有材质/状态/炉批或聚合物批号、准确品牌料号、尺寸/表处/清洗符合性文件。Ensinger只指PEEK原料来源，不冒充已承接本件加工； 框架和钢件加工厂待采购批准。任何代料、涂层或弹簧换型必须重新评审。

# 04 / 自制件加工工序

对象 | 工序与关键控制
左右框架 | 6061-T651整料→粗铣→按供方工艺稳定化评估→建立A座面/B导孔/C止挡基准→同装夹精加工两导孔、键和孔坐标 →M3攻丝→去毛刺→遮蔽→无染料阳极15±5μm、无镍封孔→清洗→成品复测。
框架遮蔽 | Ø12H7导孔全长、全部螺纹孔和局部O处顶面Ø12接地圆。座面/键尺寸为表处后尺寸，需预留膜层；不允许现场 随意打磨修配。端子接触区保持无膜并作连续性复检。
PEEK槽块 | TECAPEEK SX natural同批原料→底面/外形→通孔→槽口和底部键槽→受控去毛刺→接触面/边缘检验→独立清洗、 保护槽唇。不得改用碳填充料或涂层。
阶梯导杆 | 316L棒料→车中段、肩面和端段→端部M4孔→铣接地平面并攻M3→滑动段精磨10h9、Ra0.1–0.3→倒角/钝化→清洗 →直线度、肩距、有效牙和接地平面检验。
叉形端盖 | 316L一体车铣；孔底、内孔轴、叉尖需同基准关联。不得焊接叉齿或靠切短叉齿调行程。验内孔深8、叉长22、 两尖共面及端壁。
棱边/盲孔 | 一般金属棱边C0.2±0.1；PEEK接触边R0.05±0.02。刀具半径、倒角或钻尖与关键尺寸有冲突时停止，不以隐藏 特征为由自行扩大。

### 所有加工及脏装配在洁净操作区外完成。粗糙度须用可比方法记录，不能用“抛光”替代数值要求。零件标识放非接触、非 配合、非导电接触区域；标记不得产生残留颗粒或溶剂污染。

# 05 / 衬套、弹簧与接地线束

## 压装衬套

每框架2只JSM-1012-20。检壳孔12.000–12.018后，用平头压头和刚性支撑同轴压入；禁止敲击、胶粘、加油或压后铰

### 孔。外端齐平至内缩0.05，内端不得突出妨碍金属止挡。压后内径10.025–10.083，检查裂纹、翻边与滑动阻力。

## 弹簧逐只筛选

4只LP024K05S316同料号、Type316 ASTM A313；L0=44.45±1.37，k=0.072N/mm，筛选范围0.062–0.082。测

### 22/26/30mm力值与压缩外径；外径≤14.5为本治具来料装配要求，不是原厂保证。禁止截短、磨端、拉长或换刚度救卡

滞。

两簧并联/侧：名义闭合2.081N、全开3.233N。按自由长/刚度及安装长±0.20预算，最小闭合1.597N，最大开位弹簧合力

### 3.939N。加1N综合阻力得到4.939N仅条件估算。杆/盖重量相关粗筛阻力已接近1N，必须实测静摩擦及线束拖力，不能 宣称计算已验证。

## 4支路线束制备

### 2–5N/手指横向开启增量，不含支撑治具自重的负荷。首件须另外称重，并由佩戴洁净手套的实际操作者评估持握、疲劳 及防滑；不能以小开启力推断人体工学合格。

4根22AWG多股镀锡铜、PTFE绝缘线，成品外径≤1.5mm、单丝≤0.10mm、裁长1000±20mm；每根两端各TE31090，

### 合计8端子。线材按本性能规范采购，供方提交结构及批次资料，不虚构精确线材SKU。

TE31090公开目录给出M3螺柱、22–16AWG、宽5.54、长11.40、料厚0.84、筒内径最小1.65mm。铜镀锡端子选择有污

### 染风险，置于外缘之外且需清洗/见证片验证；不宣称适合所有前道工序。其简化舌片眼孔3.18和眼心距2.77是装配建模 假定，实物不符合则先改单，禁止改孔凑装。

### 由合格线束商按TE对应端子/22AWG的适配压接工具和工艺执行，记录工具、模具、压接拉脱验收和剥线长度；无对应 有效工艺时不得自制压接。禁止裸编织带、浸锡、普通胶带及暴露散股。远端接现场M3汇点；接口不同须调整线束图。

### 线从各接点向晶圆外侧引出；Ø304晶圆投影区和滑动止挡夹缝内禁入，最小弯曲半径15mm，框架侧松弛长度≥60mm。 现场独立应力释放，线不承重也不拉端子；实际净空和阻力必须在全行程检查。

# 06 / 生产装配工步与停点

步 | 执行动作 | 检查/停点
A00 | 核对同版图、BOM、序号/批次/清洗和量具；移走真实晶圆。 | 工艺/质量评审签署；无签署先评审。
A01 | 按第5页在框架外压装4衬套。 | 记录内径/齐平/裂纹；不合格停。
A02 | 工装保持双杆344中心距、接地平面朝上；两框架从两端同步套入。 | Ø14中段不可穿衬套；不强拧拉正。
A03 | 无弹簧状态保持双手实际承重姿态；装接地端子和实际线束。 | 全行程综合起动/回程阻力≤1N/侧；超限先排查。
A04 | 四PEEK槽朝内、按35/-35/145/215°落座；键不顶底。8个M3分步对称锁紧。 先用同材试件确定K1窗口；记录四点共面/槽尺 | 寸。
A05 | 已测力配对弹簧分别套轴端；用保持工装限制弹出。 | 核四只料号和测力表，装后无触轴/叉齿。
A06 | 4端盖叉齿朝内，孔底靠杆端；装M4×10。 | K2窗口先验证；有效牙/不顶底/防弹出。
A07 | G1–G4各用M3×6夹端子；所有支路独立接现场汇点。 | K3窗口验证；全行程连续性≤1Ω；不短接腕带电 阻。
A08 | 慢速空行程，测开闭端点、两手力曲线。 | 8±0.20；闭合30±0.20/开位22±0.20；每手全开 2–5N，峰值≤5N。
A09 | 完成清洗、记录和假片分阶段循环。 | 见第8–9页；不能跳到真实片。

### 异常：先由工位托住晶圆，再停止并隔离治具。悬空持片时不得调螺钉、强掰、甩动或拔接地线。弹簧拆卸须无片、有 保持工具、逐只受控卸载。维护拆装后重做关键几何、力与颗粒/ESD检查。

# 07 / 16连接清单与扭矩验证

编号 | CAD连接名 | 规格 / 类别 | 名义啮合
J01 | CAP_SCREW_1_L | M4x10 / K2 | 7mm
J02 | CAP_SCREW_1_R | M4x10 / K2 | 7mm
J03 | CAP_SCREW_2_L | M4x10 / K2 | 7mm
J04 | CAP_SCREW_2_R | M4x10 / K2 | 7mm
J05 | GROUND_SCREW_FRAME_L | M3x6 / K3 | 5.16mm
J06 | GROUND_SCREW_FRAME_R | M3x6 / K3 | 5.16mm
J07 | GROUND_SCREW_ROD_1 | M3x6 / K3 | 5.16mm
J08 | GROUND_SCREW_ROD_2 | M3x6 / K3 | 5.16mm
J09 | PAD_SCREW_01_1 | M3x12 / K1 | 4mm
J10 | PAD_SCREW_01_2 | M3x12 / K1 | 4mm
J11 | PAD_SCREW_02_1 | M3x12 / K1 | 4mm
J12 | PAD_SCREW_02_2 | M3x12 / K1 | 4mm
J13 | PAD_SCREW_03_1 | M3x12 / K1 | 4mm
J14 | PAD_SCREW_03_2 | M3x12 / K1 | 4mm
J15 | PAD_SCREW_04_1 | M3x12 / K1 | 4mm
J16 | PAD_SCREW_04_2 | M3x12 / K1 | 4mm

### K1：PEEK/铝，试验起点0.08N·m；K2：端盖/杆，起点0.20N·m；K3：端子/金属，起点0.15N·m。它们不是

## 批准扭矩。先用同批材料、表处和有效牙接头试验确定窗口，再填入工艺卡后装配。

确认落座、防转、无压痕裂纹/滑牙/咬死；24小时和100/1000次循环复检。至少保留3个同材试验连接/类别的记录作为P1筛查，不把样本量当 作统计认证。禁止直接加胶、加垫圈或换紧固件解决松动。

# 08 / 清洗、洁净与静电控制

对象 | 实施方法与验收边界
清洗起始路线 | 同批见证样验证：经现场认可的中性低残留清洗剂去残留→高纯DI充分漂洗→过滤氮气或批准方法干燥→目视/显微、 颗粒和离子残留检查。药剂浓度/温度/时间需依材料兼容性及现场规范定，不凭空给通用配方。
禁用/隔离 | 不混洗PEEK与带毛刺金属；不用硅油、喷涂润滑剂、抛光膏/普通胶带。不得对装有衬套的总成擅自烘烤或强超声。
洁净空气 | Class100意图按ISO5操作区准备；空气等级按ISO14644-1及现场采样计划测定。单件材料或供应商系列页不证明 整机动态ISO5。
晶圆污染 | 做空白/空载/持假片动作对比，统一采样量/方法并记录基线。新增颗粒、金属和离子污染阈值由工艺负责人提供； 没有阈值不可给合格结论。
金属导电 | G1–G4各金属部件至现场公共点≤1Ω为工程连续性目标，覆盖全行程；不靠衬套、弹簧、氧化膜或滑动面通电。现 场ESD负责人批准与公共点的连接。
绝缘体离子化 | PEEK/iglidur绝缘表面无法仅靠金属接地消电。工位持续离子化覆盖，工作位离子平衡±10V目标；晶圆表面电位另 测，目标绝对值≤10V。
测量记录 | 仪器型号/校准、量程/距离、晶圆膜层/厚度、动作阶段、温湿度和测量不确定度。±10V为开发目标，不是器件损 伤阈值，也不承诺绝对0V。
包装 | 合格后使用现场批准低析出双层洁净袋；避开槽唇受力，标识序号、版次、批次、清洗日期。开包/移交规程由现 场质量负责。

# 09 / 首件验收、操作与维护

阶段 | 数量/动作 | 通过条件
尺寸 | 1台关键尺寸100%；5种自制件全尺寸记录 | 图纸尺寸、粗糙度、螺纹、衬套压入及材料表处均有记录。
动作 | 空载先100次，再1000次开发耐久筛查 | 无裂纹、松动、卡滞、可见屑；0/100/1000次复测力、行程 和接地。不是寿命额定值。
厚度边界 | 0.50/0.775/0.90mm各1假片，先测直径和翘曲，再各 100次取放 | 四点承托，接触均限外缘2mm，显微对比无新增崩边/划痕； 不在悬空调节。
单侧/偏载 | 无片先慢速单侧先开、合理手持偏载和线束扰动 | 能受控恢复，无卡滞/夹线；不做自由跌落或猛烈松手。
污染/ESD | 同现场、代表膜层和实际动作，空白对照 | 按第8页阈值与原始测量判定；任一无阈值或未测即未通过。
使用准入 | 设计、工艺、质量、使用方逐项签署 | 先批准代表性监控/非良品，再按现场流程决定真实工艺片。 当前未获得这些批准。

## 操作顺序

### 取片：片在合适载台上支撑→双手受控张开→水平对准外缘→缓慢闭合至金属止挡→确认4点有效承托→小行程试抬→水平转 移。放片：载台充分承托→缓慢张开→退出。不得让闭合弹簧冲击晶圆边缘。

## 每班前与维护后

### 确认端盖/螺钉无松动、槽唇无缺损、衬套不移位、线束无损、离子化和接地量测有效。任何肉眼可见屑、异常阻力、电 位超限、划伤或碰撞立即隔离并记录。不要在晶圆上方拆件。维护后需清洗及重验；未建立验证周期前每次使用前检查。

# 10 / 首件记录与未关闭事项

号 | 对象 | 验收要求 | 方法
I01 | 壳孔4处 | 12.000–12.018mm；两孔344±0.01 | 孔径规/CMM
I02 | 衬套4处 | 装后孔10.025–10.083；外端内缩0–0.05 | 低测力内径/深度
I03 | 杆滑动面 | 9.964–10.000；Ra0.1–0.3μm | 外径千分尺/粗糙度
I04 | 杆肩距/总长 | 372±0.03 / 488±0.05 | CMM/长度量仪
I05 | PEEK槽 | 高1.20±0.02；深1.60±0.02 | 光学/低测力
I06 | 定位键槽 | 图5/11；侧隙0.02–0.04，顶隙0.05–0.10 | 组合尺寸算术检查
I07 | 闭合功能尺寸 | 槽后壁R150.20±0.10；内缘R148.60±0.10；共面0.05 | CMM/专用量规
I08 | 单侧行程/簧长 | 8±0.20；30±0.20/22±0.20 | 位移表
I09 | 阻力/手力 | 无簧综合≤1N/侧；全开2–5N/手；峰值≤5N | 力传感器+位移记录
I10 | 等电位/电位 | 4支路≤1Ω；离子平衡和晶圆电位各±10V目标 | 连续性/电位量测
I11 | 污染/损伤 | 按现场批准限值；无新增崩边/划痕 | 空白和动作见证片
I12 | 接头/清洗 | 16连接窗口/实际扭矩、24h及循环复检；清洗有效 | 独立工艺卡/原始数据

## 工艺停点：实际螺钉扭矩窗口、TE实物接口和线束压接工艺、现场污染阈值/清洗参数、真实晶圆直径翘曲与 膜层。需实物和现场证据关闭，不由进一步CAD计算代签。先完成制造评审再加工首件；完整量产放行仍未完

成。

# 11 / 来源索引与变更追溯

S01 Ensinger TECAPEEK SX natural — 半导体级未填充 PEEK 原料身份；不证明本治具工艺合格

打开官方来源 (https://www.ensingerplastics.com/en/shapes/peek-tecapeek-sx-natural)

S02 igus JSM-1012-20 — 10×12×20 衬套、压入后孔径、壳孔和轴公差；官网公开页面读取

打开官方来源 (https://www.igus.eu/iglidur-ibh/sleeve-bearings/product-details/iglidur-j-m?artnr=JSM-1012-20)

S03 igus J 材料技术数据 — Ra 0.1-0.3 μm、对钢动摩擦系数0.06-0.18；不是本治具静摩擦保证值

打开官方来源 (https://www.igus.com/info/material-iglidur-j?C=ES&L=es)

S04 Lee Spring LP 024K 05 S316 — 首选弹簧准确料号、材料、尺寸、公差；官网直接读取

打开官方来源 (https://www.leespring.com/product/compression-spring-lp024k05s316-stainless-steel-type-316)

S05 Lee Spring LP 024K 04 S316 — 较短候选弹簧对比，最终不选

打开官方来源 (https://www.leespring.com/product/compression-spring-lp024k04s316-stainless-steel-type-316)

S06 Lee Spring official catalog — 历史目录纸页47/PDF第49页交叉核对，不作为当期库存或交期证明

打开官方来源 (https://www.leespring.com/sites/default/files/2019-07/Lee_Spring_Catalog_US_Eng.pdf)

S07 Bossard BN 612 — ISO4762全牙A4系列；具体SKU及A4-70证书需订单确认，非316L承诺

打开官方来源 (https://www.bossard.com/at-de/eshop/schrauben-mit-innenantrieb/zylinderschrauben-mit-innensechskant-ohne-schaft/p/612/)

S08 Outokumpu Supra 316L/4404 — 316L/S31603/1.4404身份识别，不证明棒料已购或加工商已批准

打开官方来源 (https://www.outokumpu.com/en/products/product-ranges/supra/supra-316l-4404)

S09 ESDA Principles of ESD Control — 导体等电位与绝缘体离子化的区别；本文±10V为工程目标，非该标准限值

打开官方来源 (https://www.esda.org/esd-overview/esd-fundamentals/part-2-principles-of-esd-control/)

S10 ISO 14644-14:2026 public scope — 设备空气粒子适用性评价；不替代晶圆颗粒、ESD、材料或清洗资格

打开官方来源 (https://www.iso.org/standard/91615.html)

S11 FreeCAD Fasteners Workbench — 现有16颗ISO4762 CAD几何来源；commit 79a06dc067b57ebc89532be835704eb2af5da96c，非实 物供应商

打开官方来源 (https://github.com/shaise/FreeCAD_FastenersWB)

S12 Lee Spring spring diameter expansion note — 压缩会改变弹簧外径，需叠加自由态外径公差；不可只验名义包络

打开官方来源 (https://www.leespring.com/sites/default/files/pdf/Lee%20Spring%20-%20WhitePaper%20-%20Spring%20Design%20General%20Consideration_US.pdf)

S13 TE SOLISTRAND 1773464-2 QRG — 31090目录尺寸、材料和接线范围；非洁净室认证

打开官方来源 (https://www.te.com/content/dam/te-com/documents/industrial-automation-and-control/global/1773464-2_QRG_SOLISTRAND_08-2013.pdf)

检索：STEP.parts对JSM、Lee Spring以及新增31090返回0条；本地核验目录为空。结构化未命中不等于市场不存在。转用厂商官网参数，经 用户“允许简化模型，继续出图”授权制作明确标识的简化表示，未绕过下载验证码。

主要P1改动：壳孔10.10→12H7，加入4衬套；选定K05弹簧；4专用接地点及4端子/4螺钉；材料/工艺条件、公差和记录表配套。旧R2留存。 没有对外发送图纸、询价或采购。

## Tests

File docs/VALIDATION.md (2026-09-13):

# Evidence and qualification status

## Historical CAD statements are not independent public test evidence

The unchanged assembly manual cites historical CAD checks associated with the original P1D1 engineering session. Detailed internal test reports and numerical validation records are **not included in this public repository**. Those historical statements cannot be independently reproduced from the published integrity checker. This release does not claim an independent CAD revalidation, manufacturing approval or physical wafer qualification.

Native file identity is recorded in [provenance.json](../validation/provenance.json). These are file hashes and publication mappings, not test results. The geometry, tolerances, BOM and manufacturing requirements were not changed during publication packaging.

## Current publication checks

`tools/verify_release.py` checks the release manifest, SHA-256 values, native ZIP/XML container structure, base64 JSON parameter syntax, STEP boundaries, CSV/JSON BOM agreement, BOM totals, 24 drawing files, local Markdown links, and selected path/credential patterns. It does not load a CAD kernel or execute embedded data. Tests exercise failure handling as well as the current package.

The release manifest deliberately excludes itself and `SHA256SUMS.txt` from its file list. These two index files are not self-authenticating; a trusted Git commit or independently delivered digest is still needed for authenticity. Passing checks does not guarantee the absence of every conceivable secret, legal encumbrance or design defect.

## Open engineering gates

Manufacturing capability / drawing approval; physical terminal compatibility and crimping; joint torque windows; hand-force / friction / harness behavior; operator load and fatigue; cleanroom particles and metal / ionic contamination; cleaning; wafer surface potential and ESD; wafer edge integrity at thickness limits; life testing and maintenance intervals. None are closed by publishing this repository.

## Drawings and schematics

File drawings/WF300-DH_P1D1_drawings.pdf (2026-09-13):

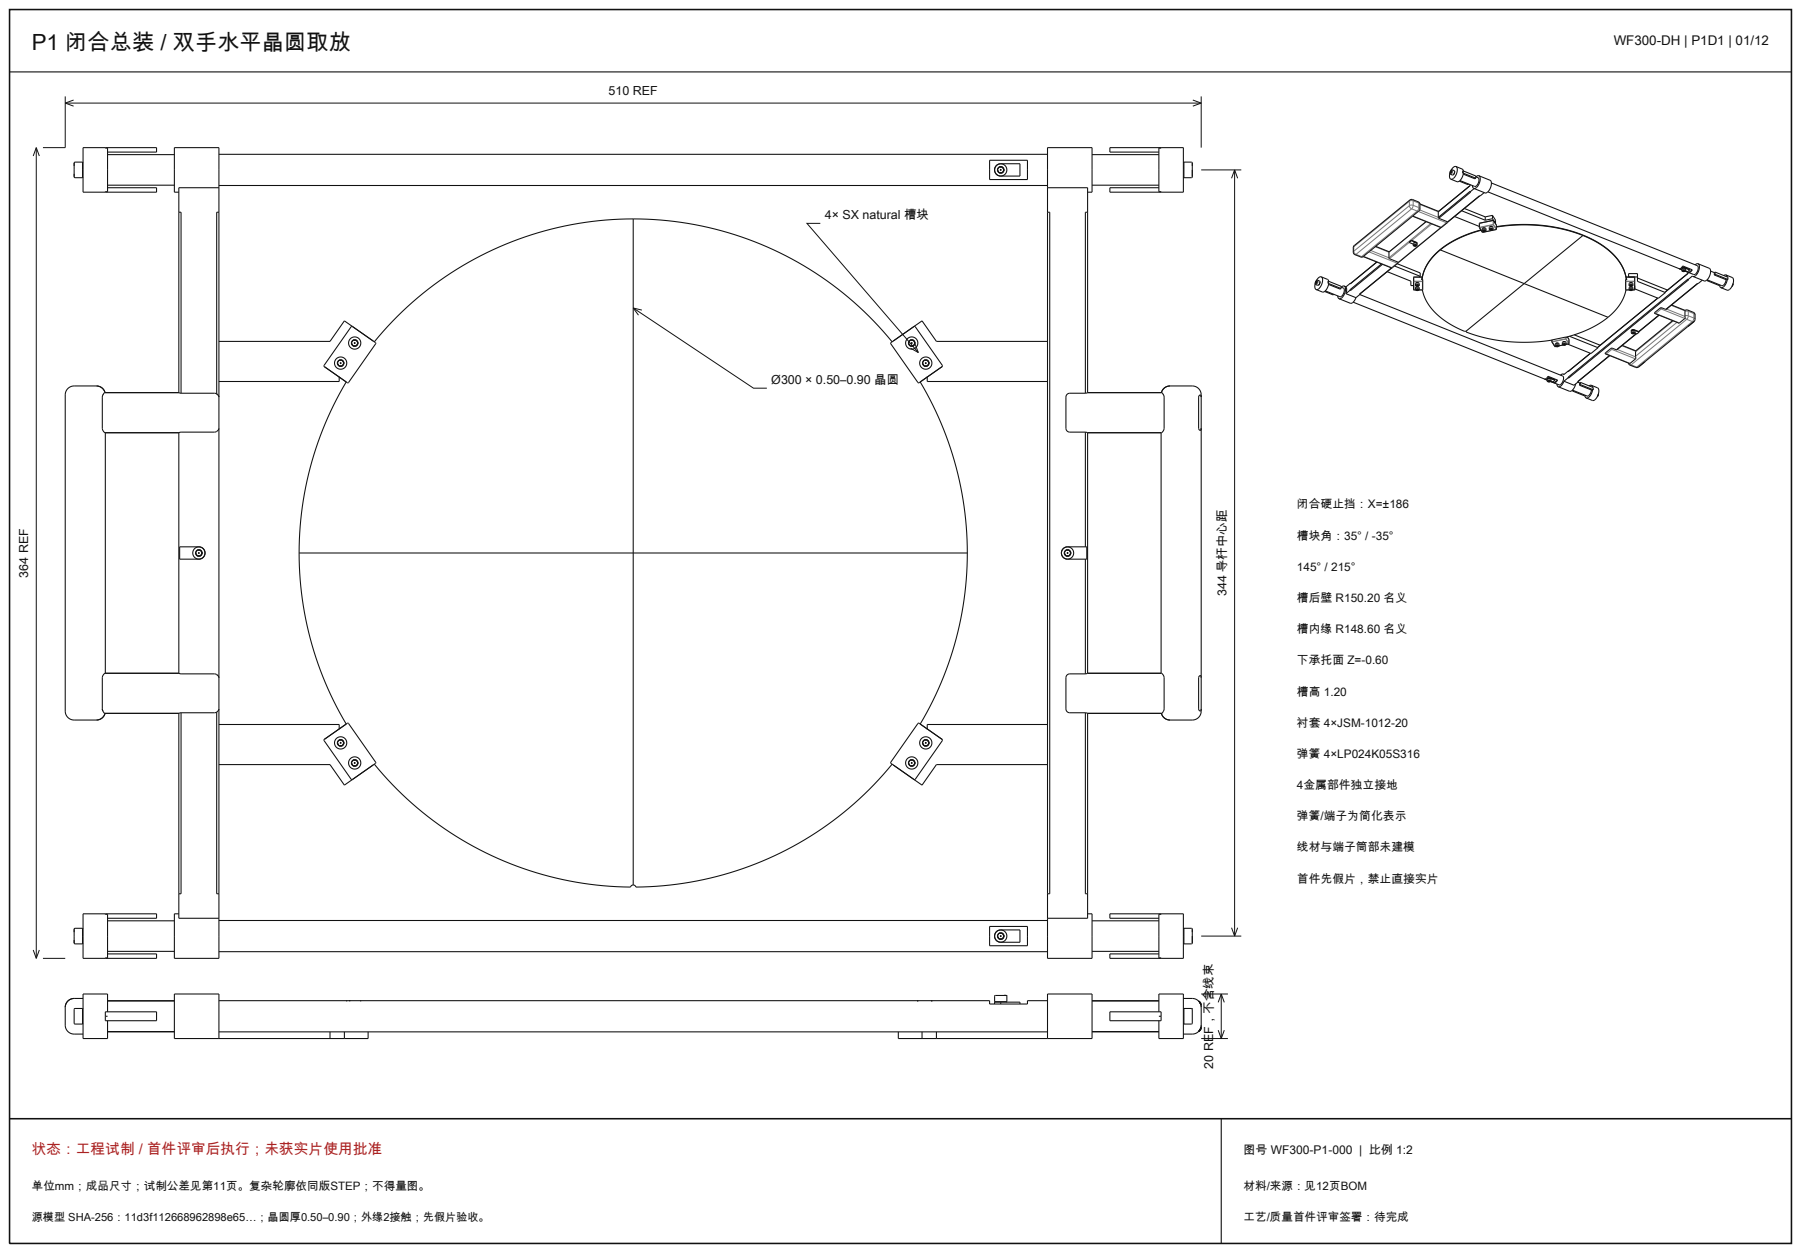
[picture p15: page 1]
P1 闭合总装 / 双手水平晶圆取放; 材料/来源：见12页BOM; 510 REF; 364 REF; 344 导杆中心距; 闭合硬止挡：X=±186; 槽块角：35° / -35°; 槽后壁 R150.20 名义; 槽内缘 R148.60 名义; 下承托面 Z=-0.60; 衬套 4×JSM-1012-20; 4金属部件独立接地; 弹簧/端子为简化表示; 线材与端子筒部未建模; 首件先假片，禁止直接实片; 20 REF，不含线束

4× SX natural 槽块

状态：工程试制 / 首件评审后执行；未获实片使用批准

单位mm；成品尺寸；试制公差见第11页。复杂轮廓依同版STEP；不得量图。

源模型 SHA-256：11d3f112668962898e65…；晶圆厚0.50–0.90；外缘2接触；先假片验收。

工艺/质量首件评审签署：待完成

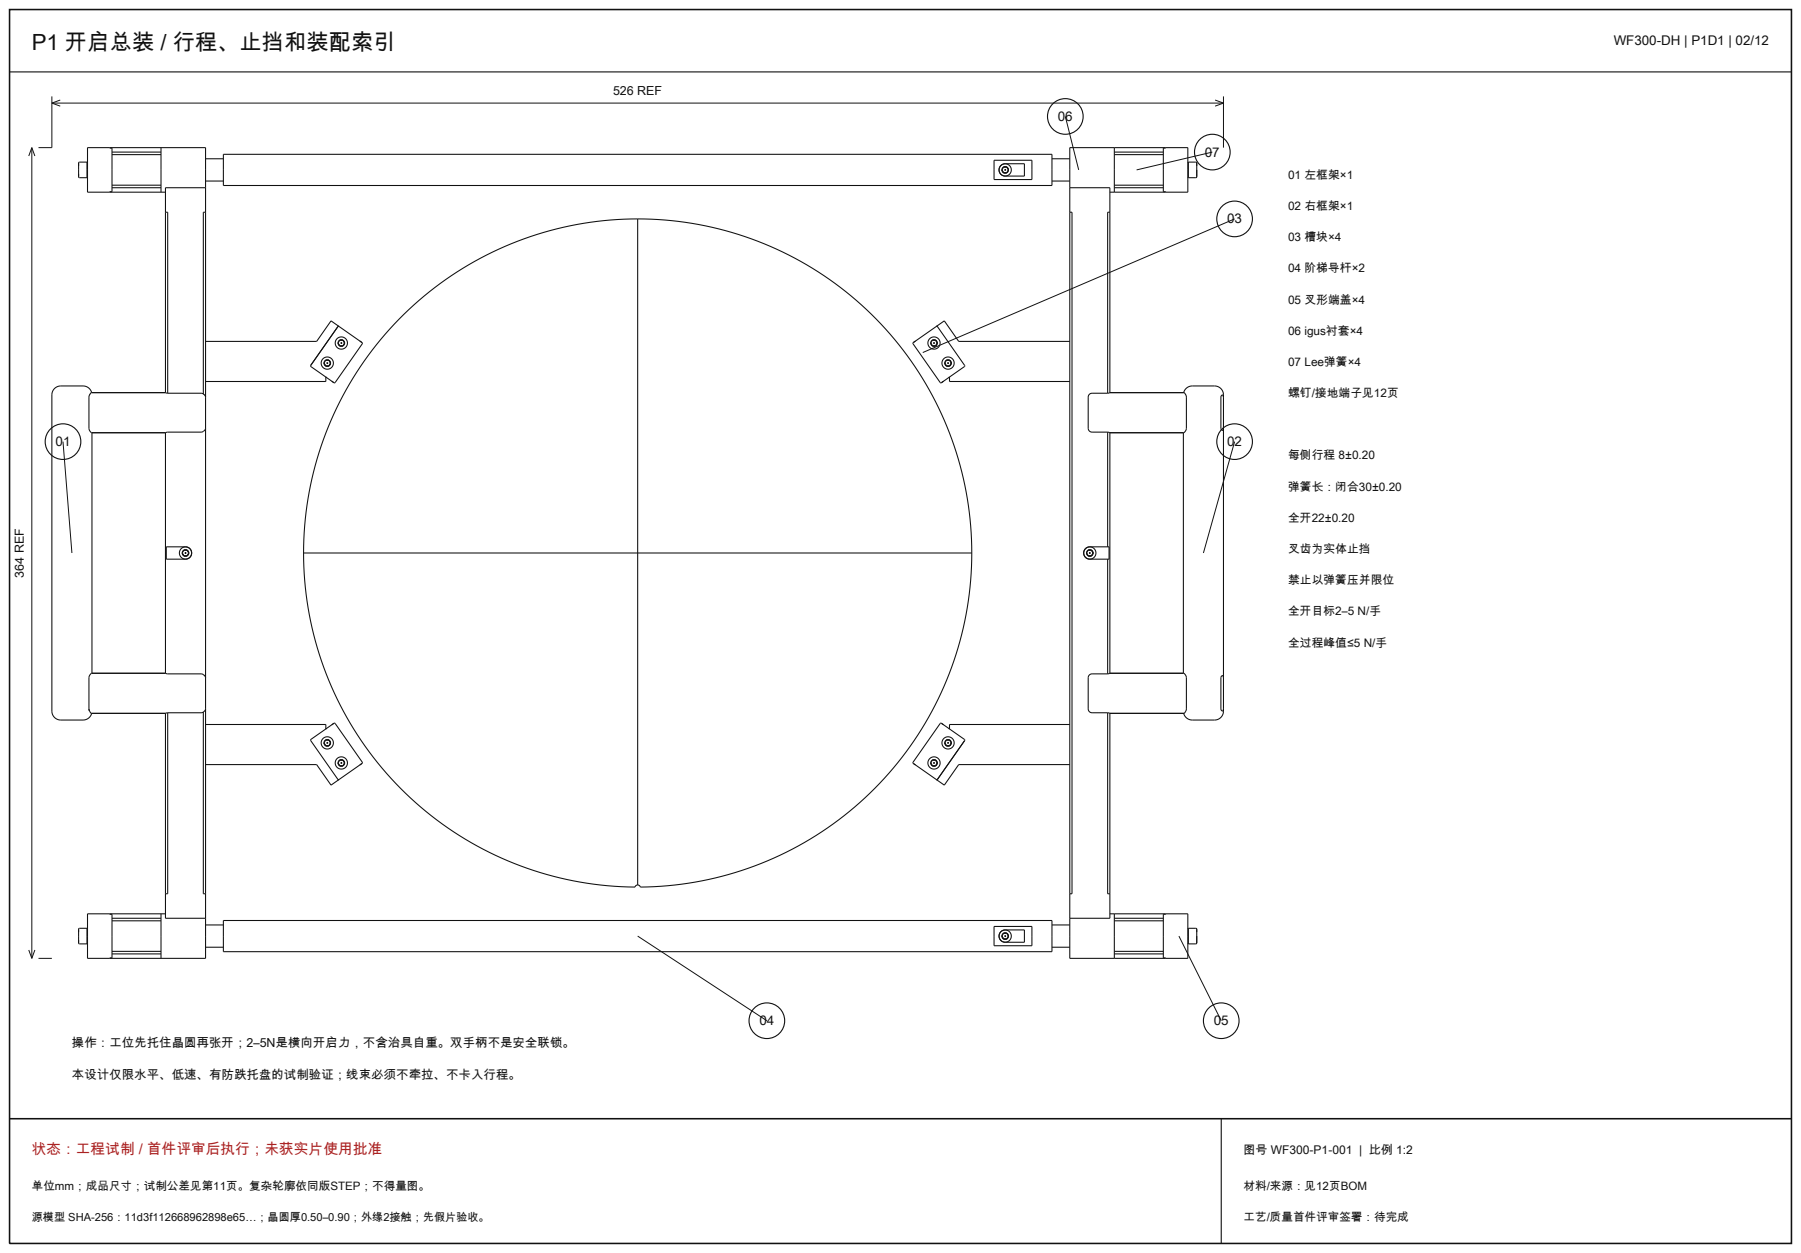
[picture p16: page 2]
P1 开启总装 / 行程、止挡和装配索引; 材料/来源：见12页BOM; 526 REF; 364 REF; 01 左框架×1; 02 右框架×1; 04 阶梯导杆×2; 05 叉形端盖×4; 06 igus衬套×4; 07 Lee弹簧×4; 螺钉/接地端子见12页; 每侧行程 8±0.20; 弹簧长：闭合30±0.20; 叉齿为实体止挡; 禁止以弹簧压并限位; 全开目标2–5 N/手; 全过程峰值≤5 N/手

操作：工位先托住晶圆再张开；2–5N是横向开启力，不含治具自重。双手柄不是安全联锁。

本设计仅限水平、低速、有防跌托盘的试制验证；线束必须不牵拉、不卡入行程。

状态：工程试制 / 首件评审后执行；未获实片使用批准

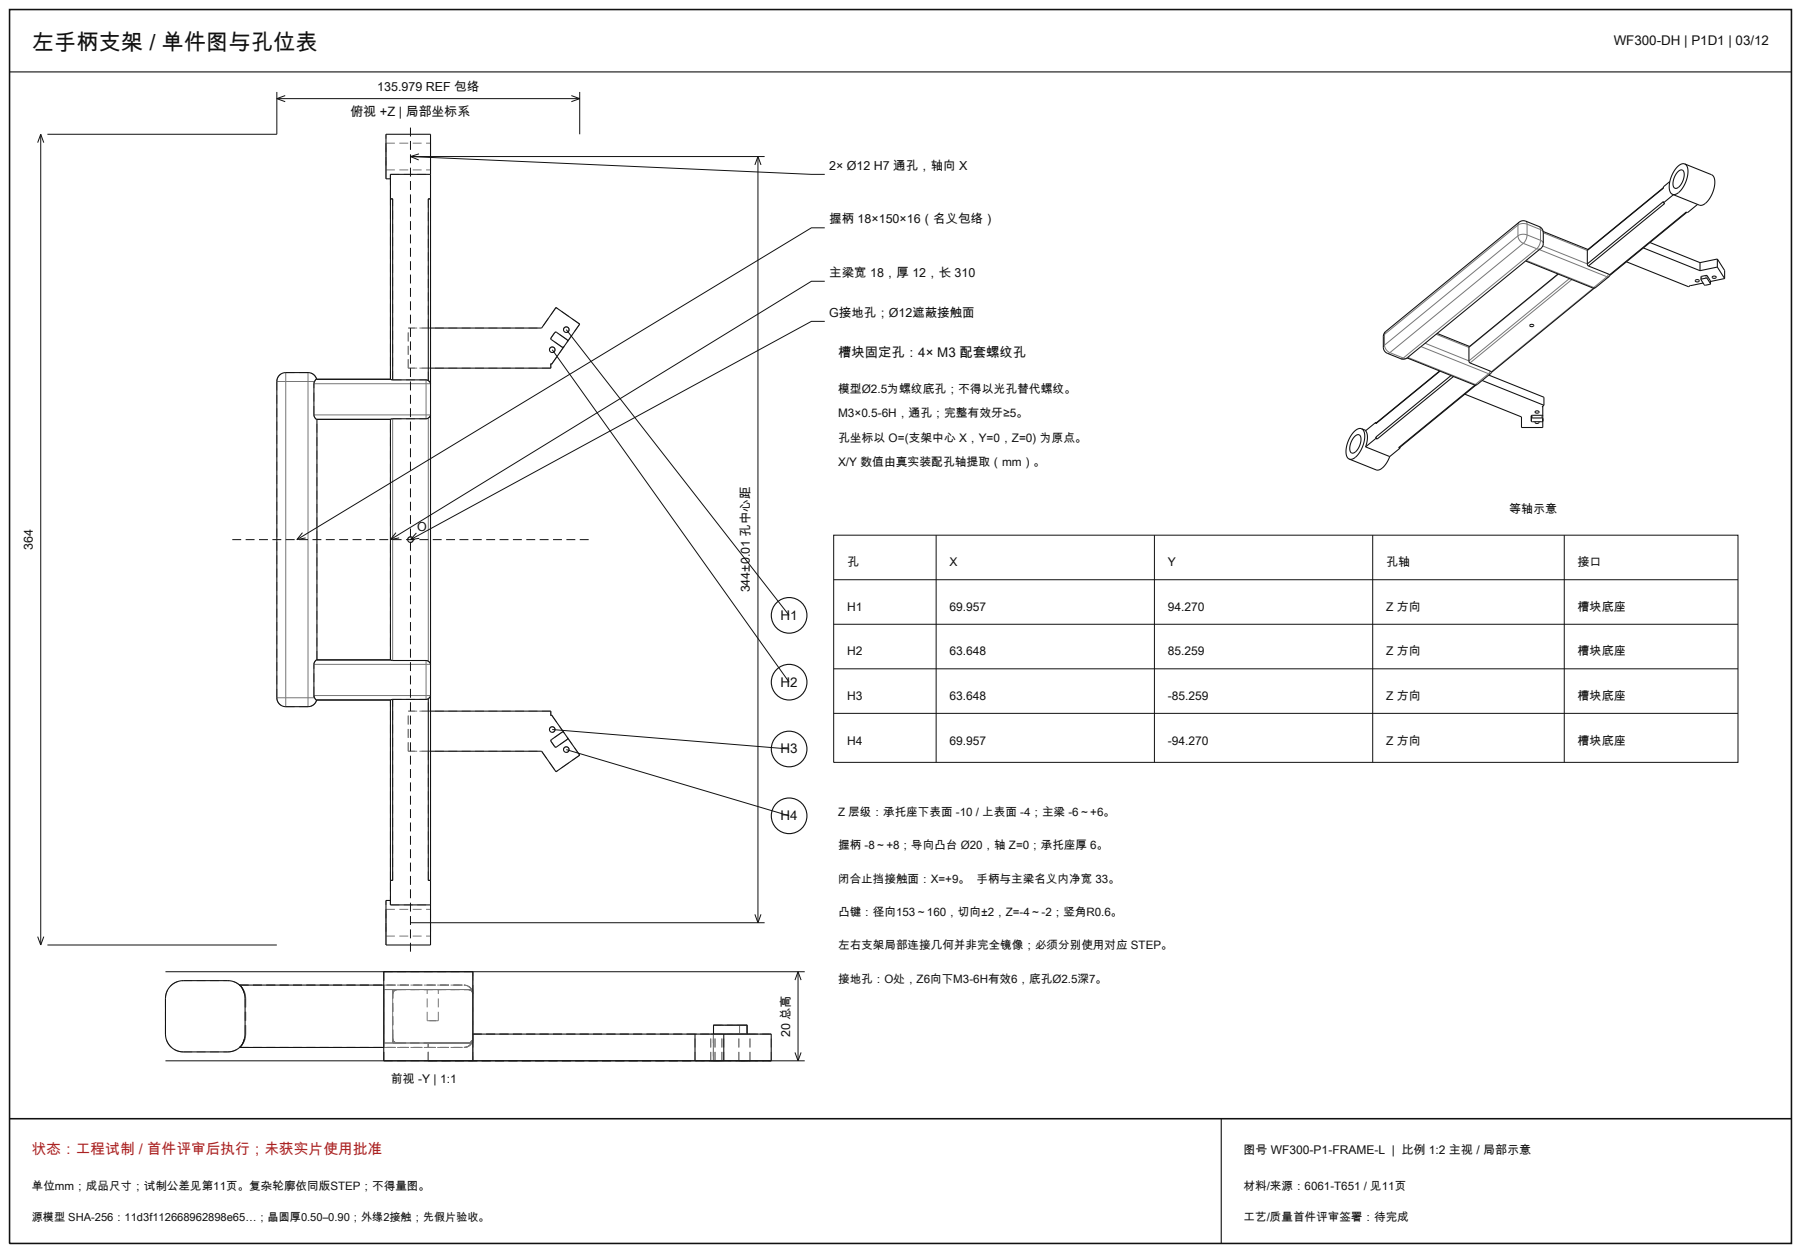
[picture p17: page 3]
左手柄支架 / 单件图与孔位表; 俯视 +Z | 局部坐标系; 孔中心距; 135.979 REF 包络; 握柄 18×150×16（名义包络）; 主梁宽 18，厚 12，长 310; 等轴示意; 槽块固定孔：4× M3 配套螺纹孔; 模型Ø2.5为螺纹底孔；不得以光孔替代螺纹。; M3×0.5-6H，通孔；完整有效牙≥5。; X/Y 数值由真实装配孔轴提取（mm）。; 槽块底座 H1; 槽块底座; Z 层级：承托座下表面 -10 / 上表面 -4；主梁 -6～+6。; 闭合止挡接触面：X=+9。 手柄与主梁名义内净宽 33。; 凸键：径向153～160，切向±2，Z=-4～-2；竖角R0.6。; 接地孔：O处，Z6向下M3-6H有效6，底孔Ø2.5深7。; G接地孔；Ø12遮蔽接触面

孔坐标以 O=(支架中心 X，Y=0，Z=0) 为原点。

握柄 -8～+8；导向凸台 Ø20，轴 Z=0；承托座厚 6。

左右支架局部连接几何并非完全镜像；必须分别使用对应 STEP。

状态：工程试制 / 首件评审后执行；未获实片使用批准

图号 WF300-P1-FRAME-L | 比例 1:2 主视 / 局部示意

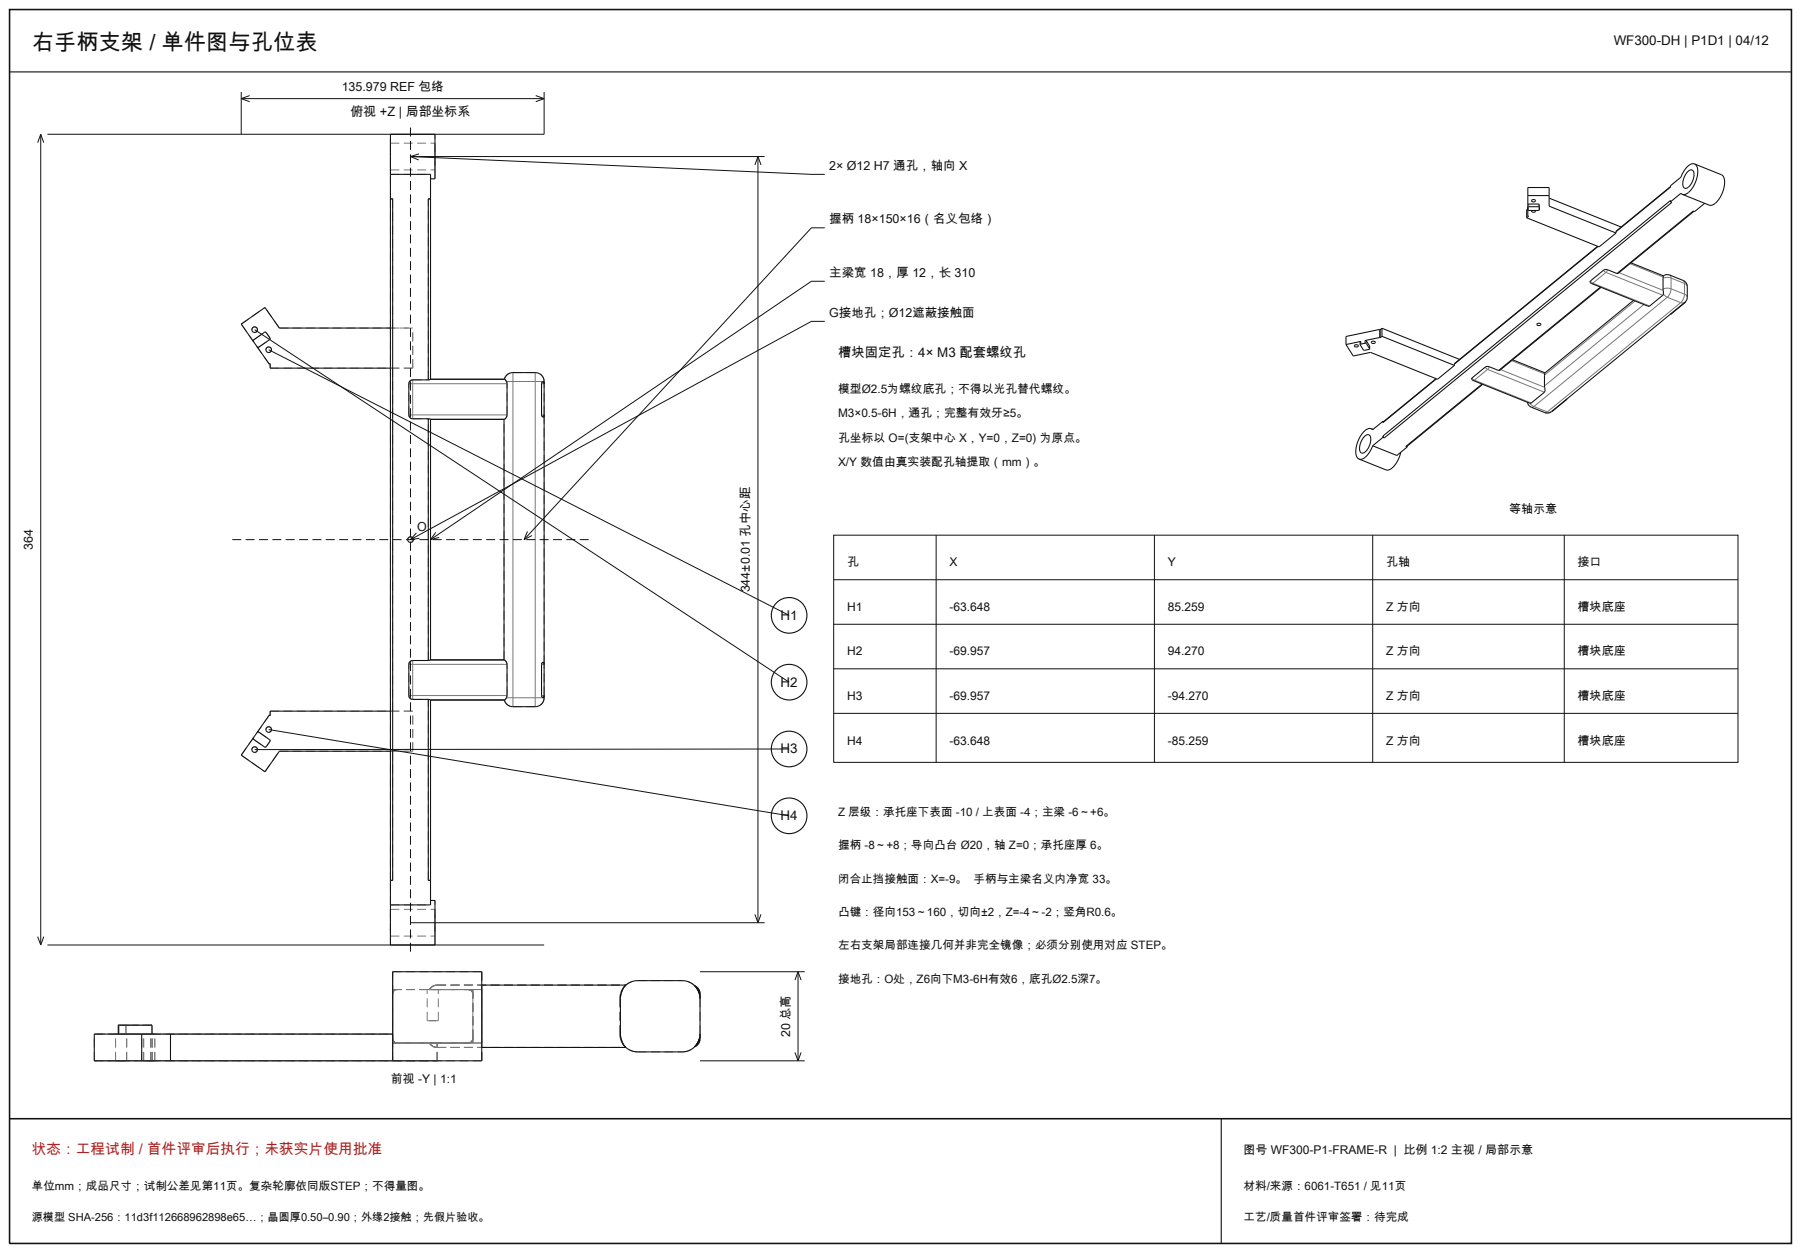
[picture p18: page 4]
右手柄支架 / 单件图与孔位表; 俯视 +Z | 局部坐标系; 孔中心距; 135.979 REF 包络; 握柄 18×150×16（名义包络）; 主梁宽 18，厚 12，长 310; 等轴示意; 槽块固定孔：4× M3 配套螺纹孔; 模型Ø2.5为螺纹底孔；不得以光孔替代螺纹。; M3×0.5-6H，通孔；完整有效牙≥5。; X/Y 数值由真实装配孔轴提取（mm）。; 槽块底座 H1; 槽块底座; Z 层级：承托座下表面 -10 / 上表面 -4；主梁 -6～+6。; 闭合止挡接触面：X=-9。 手柄与主梁名义内净宽 33。; 凸键：径向153～160，切向±2，Z=-4～-2；竖角R0.6。; 接地孔：O处，Z6向下M3-6H有效6，底孔Ø2.5深7。; G接地孔；Ø12遮蔽接触面

孔坐标以 O=(支架中心 X，Y=0，Z=0) 为原点。

握柄 -8～+8；导向凸台 Ø20，轴 Z=0；承托座厚 6。

左右支架局部连接几何并非完全镜像；必须分别使用对应 STEP。

状态：工程试制 / 首件评审后执行；未获实片使用批准

图号 WF300-P1-FRAME-R | 比例 1:2 主视 / 局部示意

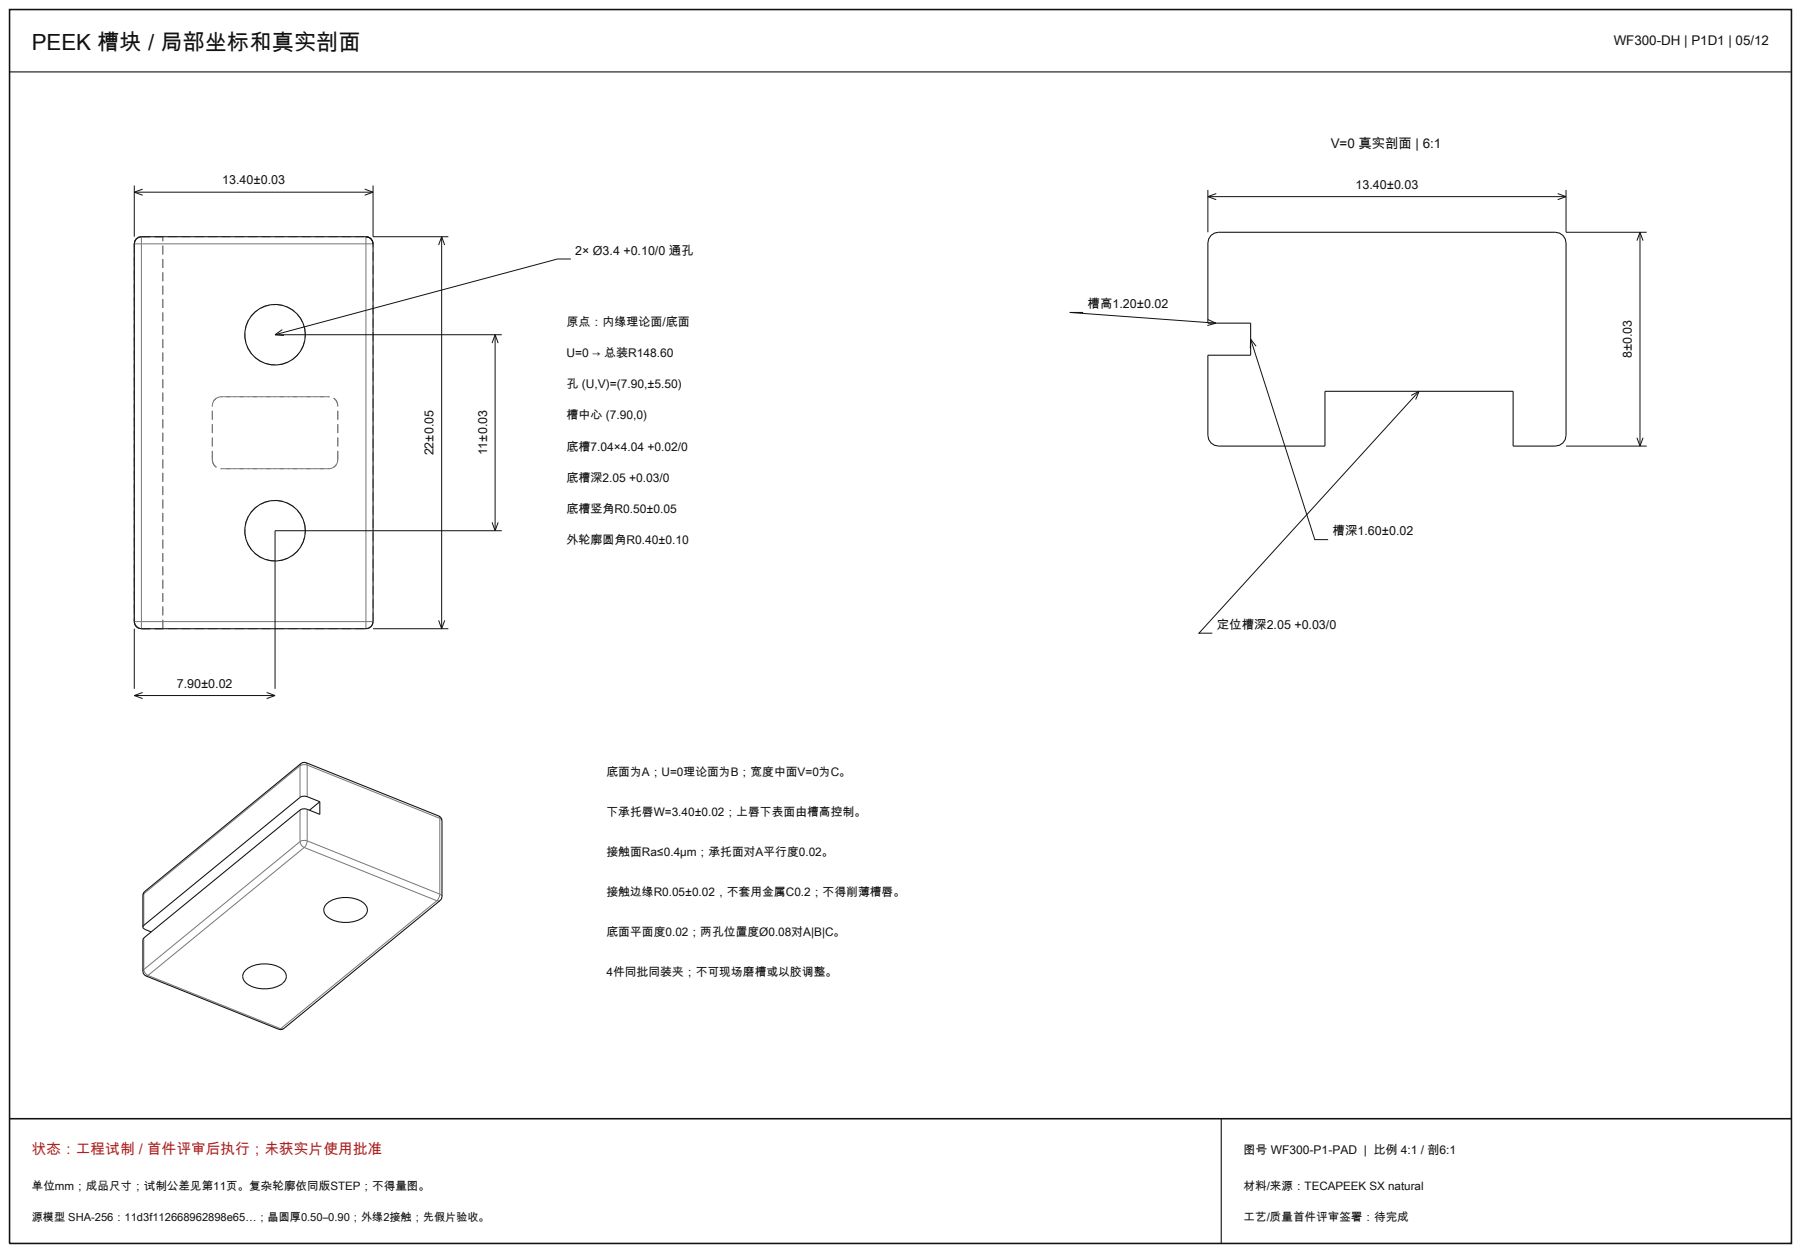
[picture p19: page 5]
PEEK 槽块 / 局部坐标和真实剖面; U=0 → 总装R148.60; 槽中心 (7.90,0); 底槽深2.05 +0.03/0; 底槽竖角R0.50±0.05; 外轮廓圆角R0.40±0.10; V=0 真实剖面 | 6:1; 定位槽深2.05 +0.03/0; 底面为A；U=0理论面为B；宽度中面V=0为C。; 下承托唇W=3.40±0.02；上唇下表面由槽高控制。; 接触面Ra≤0.4μm；承托面对A平行度0.02。; 接触边缘R0.05±0.02，不套用金属C0.2；不得削薄槽唇。; 底面平面度0.02；两孔位置度Ø0.08对A|B|C。; 4件同批同装夹；不可现场磨槽或以胶调整。

原点：内缘理论面/底面

状态：工程试制 / 首件评审后执行；未获实片使用批准

图号 WF300-P1-PAD | 比例 4:1 / 剖6:1

材料/来源：TECAPEEK SX natural

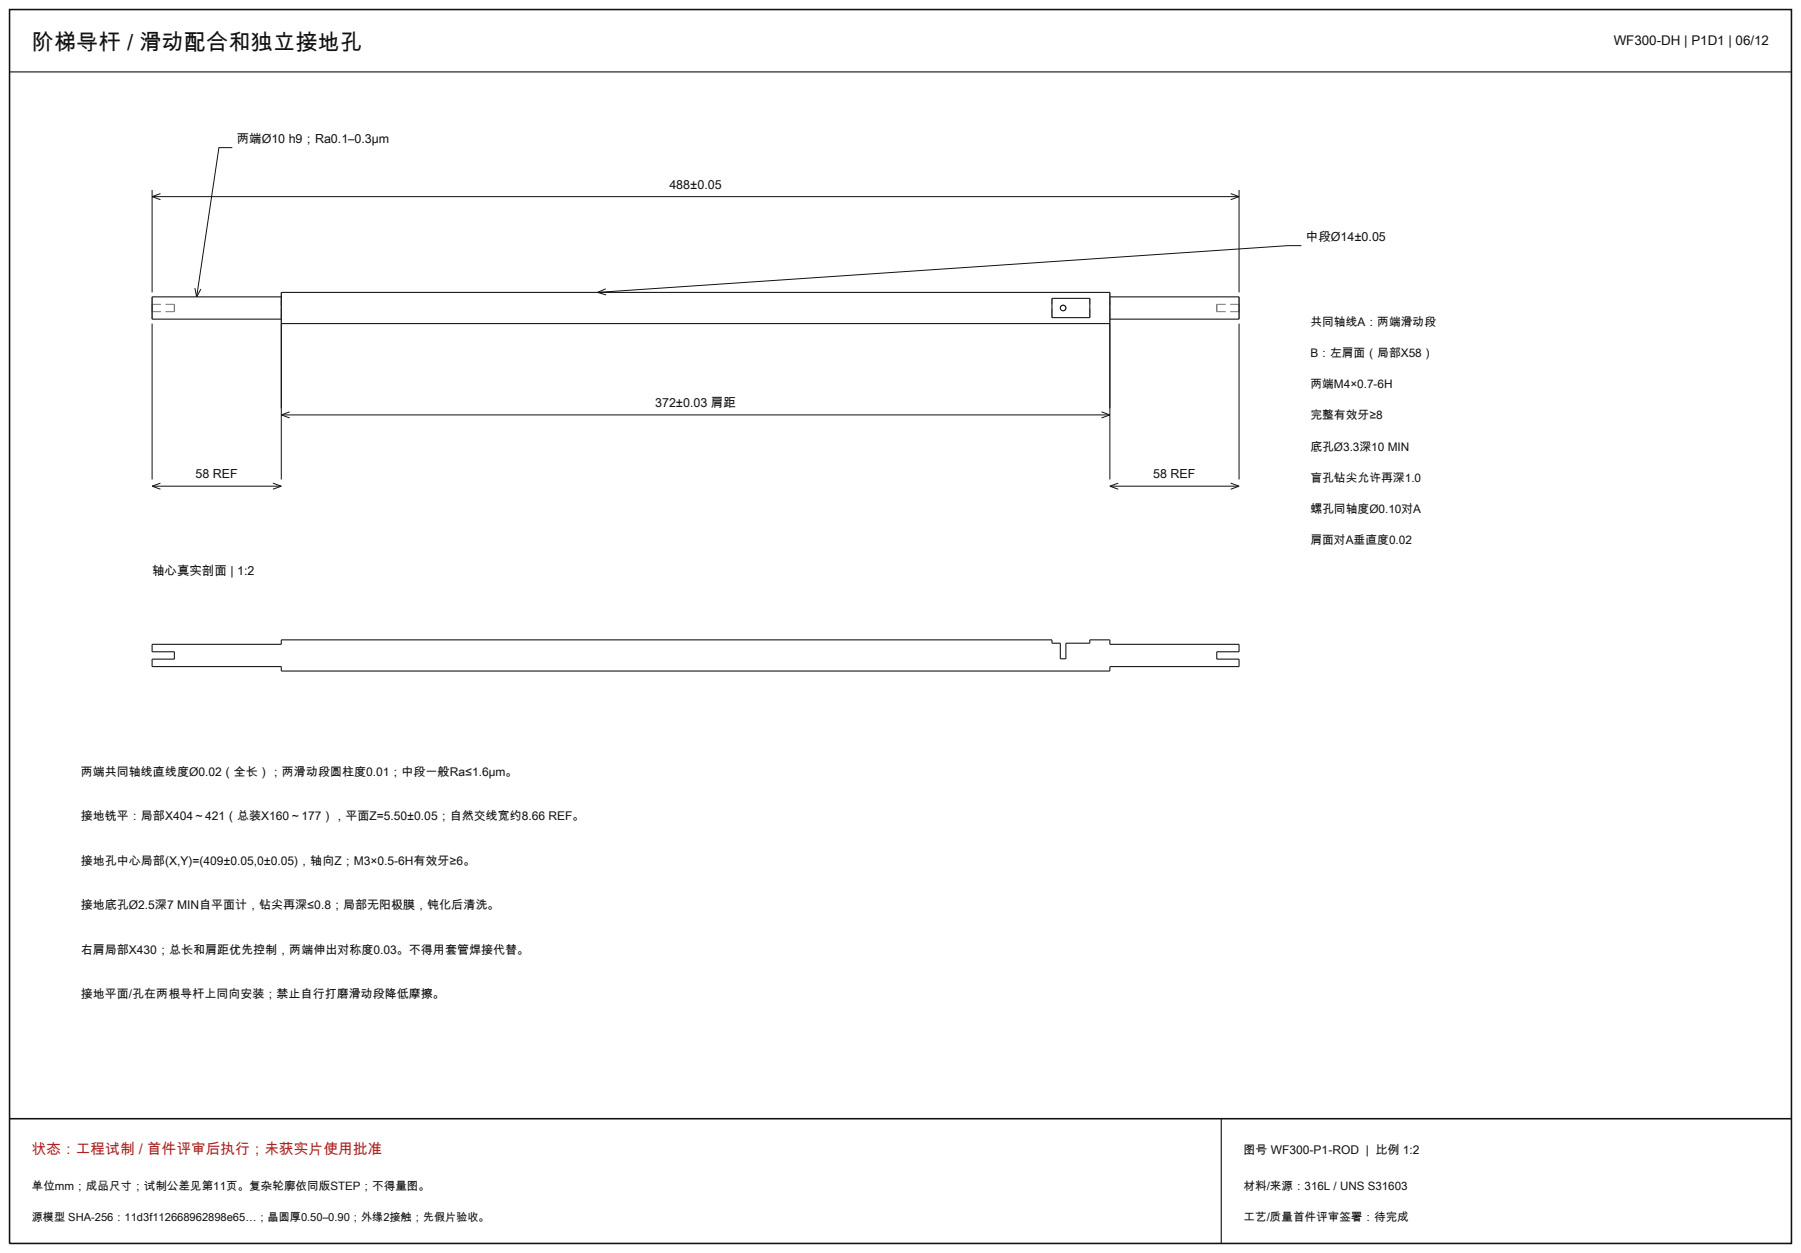
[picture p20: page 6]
阶梯导杆 / 滑动配合和独立接地孔; 58 REF; 中段Ø14±0.05; 两端Ø10 h9；Ra0.1–0.3μm; 共同轴线A：两端滑动段; B：左肩面（局部X58）; 两端M4×0.7-6H; 完整有效牙≥8; 底孔Ø3.3深10 MIN; 盲孔钻尖允许再深1.0; 螺孔同轴度Ø0.10对A; 肩面对A垂直度0.02; 轴心真实剖面 | 1:2; 两端共同轴线直线度Ø0.02（全长）；两滑动段圆柱度0.01；中段一般Ra≤1.6μm。; 接地孔中心局部(X,Y)=(409±0.05,0±0.05)，轴向Z；M3×0.5-6H有效牙≥6。; 右肩局部X430；总长和肩距优先控制，两端伸出对称度0.03。不得用套管焊接代替。

接地铣平：局部X404～421（总装X160～177），平面Z=5.50±0.05；自然交线宽约8.66 REF。

接地底孔Ø2.5深7 MIN自平面计，钻尖再深≤0.8；局部无阳极膜，钝化后清洗。

接地平面/孔在两根导杆上同向安装；禁止自行打磨滑动段降低摩擦。

状态：工程试制 / 首件评审后执行；未获实片使用批准

图号 WF300-P1-ROD | 比例 1:2

材料/来源：316L / UNS S31603

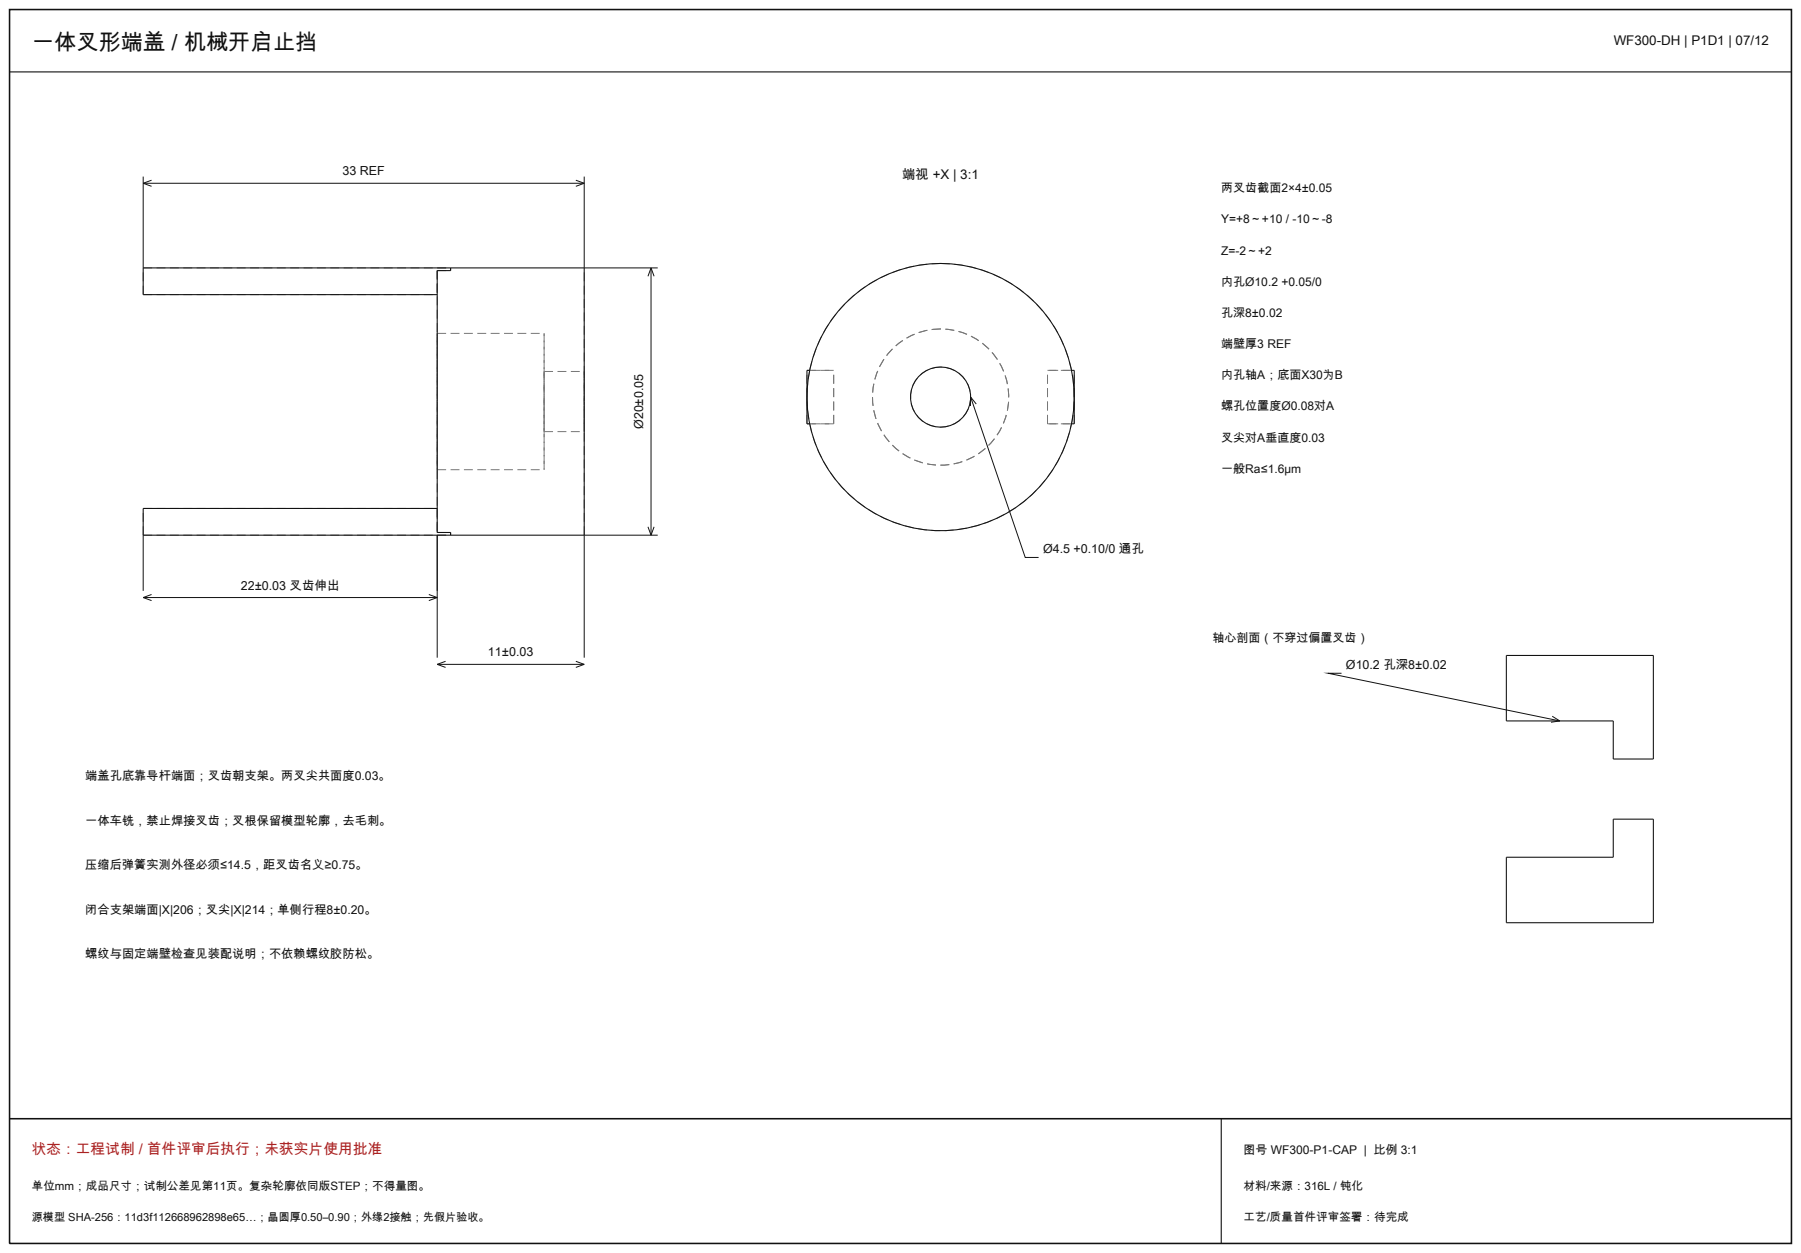
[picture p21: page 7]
一体叉形端盖 / 机械开启止挡; 33 REF; 22±0.03 叉齿伸出; 两叉齿截面2×4±0.05; 内孔Ø10.2 +0.05/0; 端壁厚3 REF; 内孔轴A；底面X30为B; 螺孔位置度Ø0.08对A; 叉尖对A垂直度0.03; 一般Ra≤1.6μm; 轴心剖面（不穿过偏置叉齿）; 端盖孔底靠导杆端面；叉齿朝支架。两叉尖共面度0.03。; 压缩后弹簧实测外径必须≤14.5，距叉齿名义≥0.75。; 闭合支架端面|X|206；叉尖|X|214；单侧行程8±0.20。; 螺纹与固定端壁检查见装配说明；不依赖螺纹胶防松。

一体车铣，禁止焊接叉齿；叉根保留模型轮廓，去毛刺。

状态：工程试制 / 首件评审后执行；未获实片使用批准

图号 WF300-P1-CAP | 比例 3:1
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
